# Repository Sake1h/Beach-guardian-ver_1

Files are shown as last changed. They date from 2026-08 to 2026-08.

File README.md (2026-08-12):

ChatGPT Image Aug 12, 2026, 03_50_27 PM

# Beach Guardian

A remotely controlled beach-cleaning rover designed to collect plastic debris from sand while allowing sand to fall back through a mesh sieve.

## Project Overview

Beach Guardian is a robotic prototype designed to help collect plastic waste from sandy environments.

The robot uses a front-mounted scoop with a mesh underside. The scoop can be lowered to collect a mixture of sand and debris. The scoop can then be raised using two servos, allowing sand to fall through the mesh while larger pieces of plastic remain in the scoop.

The robot is controlled through a local Wi-Fi web dashboard and uses two ESP32 microcontrollers.

## Estimated Project Cost

The following is an approximate estimate of the hardware cost for **Beach Guardian V1**. Prices may vary depending on the supplier, brand, and purchase quantity.

| Component | Quantity | Estimated Unit Cost | Estimated Total |
| --- | ---: | ---: | ---: |
| ESP32 Development Board | 2 | $13.00 | $26.00 |
| HC-SR04 Ultrasonic Sensor | 3 | $2.00 | $6.00 |
| L298N Motor Driver | 1 | $3.00 | $3.00 |
| DC Geared Motor | 2 | $10.00 | $20.00 |
| Robot Chassis | 1 | $15.00 | $15.00 |
| Wheels | 2 | $4.00 | $8.00 |
| Servo Motor | 2 | $4.00 | $8.00 |
| Buck Converter | 2 | $3.00 | $6.00 |
| Battery | 1 | $25.00 | $25.00 |
| 1000 µF Capacitors | 3 | $1.00 | $3.00 |
| 1.1 kΩ Resistors | 6 | $0.10 | $0.60 |
| Fuse + Holder | 1 | $3.00 | $3.00 |
| Power Switch | 1 | $2.00 | $2.00 |
| Hook-up / Jumper Wire | Assorted | $5.00 | $5.00 |
| Perfboard | 1 | $3.00 | $3.00 |
| Solder & Miscellaneous Hardware | Assorted | $8.00 | $8.00 |
| **Estimated Total** | | | **~$140 USD** |

 Cost Notes

* The two ESP32 boards were purchased for **5 OMR each**, approximately **$13 USD each**.
* The estimate represents the approximate replacement cost of the hardware used in the project.
* A large reason for the increased prices are due to current geopolitical situations which make shipping charges expensive.
* **Raspberry Pi, webcam, and USB hub are not included**, as the planned plastic/colour recognition system was removed from Beach Guardian V1.
* Development equipment such as a personal computer is not included in the project cost.

## What the Final Prototype Does

- Remote driving through a web dashboard
- Forward, backward, left and right movement
- Motor speed control using PWM
- Three ultrasonic distance sensors
- Live sensor readings displayed on the dashboard
- Two-servo scoop/sieve mechanism
- ESP-NOW communication between the two ESP32s
- 12 V battery-powered drivetrain
- 5 V regulated electronics and servo power
                   
  ChatGPT Image Aug 12, 2026, 03_50_27 PM

 ESP32 #1
- Hosts the Wi-Fi dashboard
- Reads the 3 ultrasonic sensors
- Displays sensor readings
- Receives driving commands from the dashboard
- Sends commands to ESP32 #2 using ESP-NOW

## Firmware

The ESP32 #1 firmware is contained in this repository.

Main source:
src/main.cpp

Supporting modules:
src/dashboard.cpp
src/dashboard.h
src/motors.cpp
src/motors.h

diagram for initial power supply

  ## Software

### ESP32 #1 — Sensor & Dashboard
Responsible for:
- Ultrasonic sensors
- Sensor data
- Web dashboard
- Sending motor commands

[View ESP32 #1 Code](ESP32_1_Sensors/)

### ESP32 #2 — Motor Control
Responsible for:
- Receiving commands
- PWM motor control
- L298N control
- Left/right motor operation

[View ESP32 #2 Code](ESP32_2_Motor_Control/)









full_signal_wiring_final

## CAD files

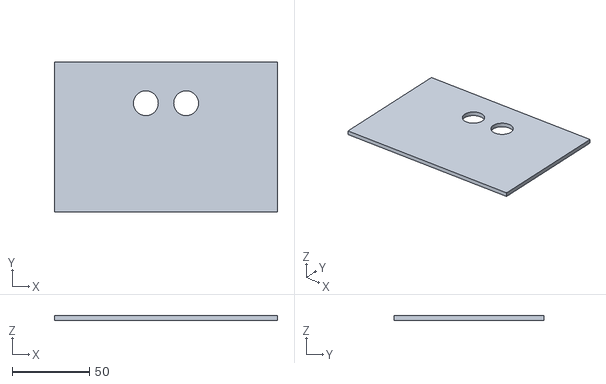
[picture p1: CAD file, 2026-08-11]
hardwarebox front_plate-Body.stl
144.0 x 97.0 x 3.00

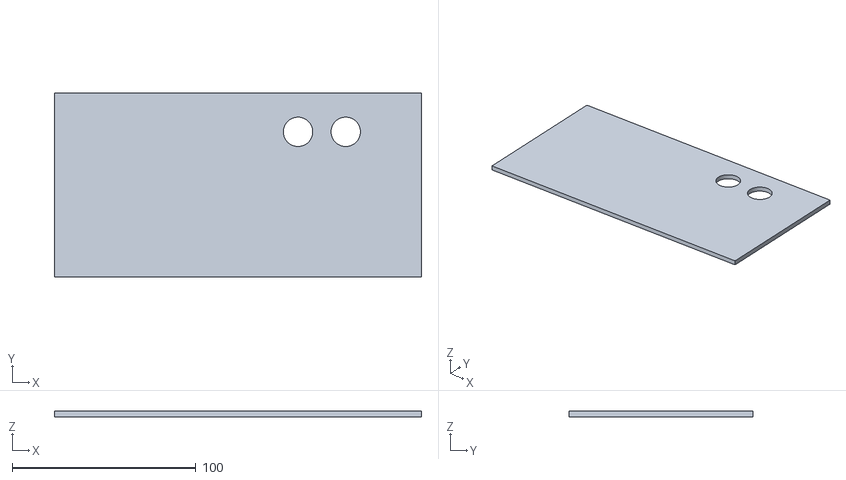
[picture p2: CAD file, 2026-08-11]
hardware box wall (side)-Body.stl
200.0 x 100.0 x 3.00

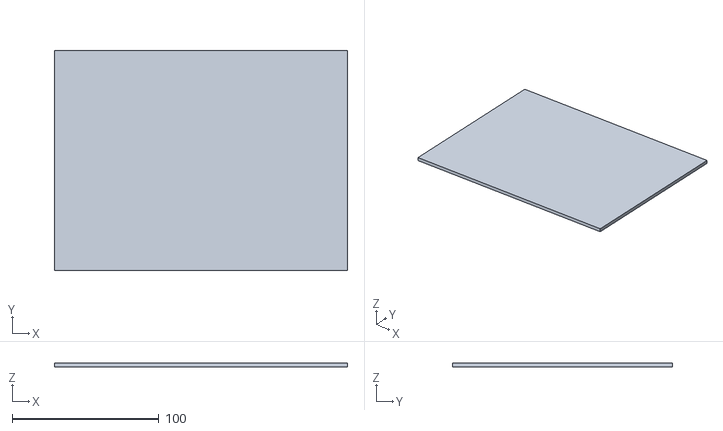
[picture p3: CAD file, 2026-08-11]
floor of hardware enclosure-Body.stl
200.0 x 150.0 x 3.00

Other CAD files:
back plate hardware box-Body.stl

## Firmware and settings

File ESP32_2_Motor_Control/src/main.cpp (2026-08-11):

#include <Arduino.h>
#include <WiFi.h>
#include <esp_now.h>
#include <esp_wifi.h>
#include <ESP32Servo.h>
//l298N pins

// Left motor
#define ENA 18
#define IN1 32
#define IN2 4

// Right motor
#define ENB 19
#define IN3 27
#define IN4 5
//servo pins

#define SERVO1_PIN 13
#define SERVO2_PIN 23

//servo positions
#define SERVO1_DOWN 90
#define SERVO1_UP   135
#define SERVO2_DOWN 90
#define SERVO2_UP   45
Servo sieveServo1;
Servo sieveServo2;
//pwm settings
#define PWM_FREQ 1000
#define PWM_RESOLUTION 8
#define PWM_CHANNEL_A 0
#define PWM_CHANNEL_B 1
//espnow
typedef struct {
    int leftSpeed;
    int rightSpeed;
    int sieveActive;
} ControlMessage;
ControlMessage receivedCommand;

//motor control function

void setMotor(
    int speed,
    int in1,
    int in2,
    int pwmChannel
) {
    speed = constrain(speed, -255, 255);
    if (speed > 0) {
        digitalWrite(in1, HIGH);
        digitalWrite(in2, LOW);
        ledcWrite(
            pwmChannel,
            speed
        );
    }
    else if (speed < 0) {
        digitalWrite(in1, LOW);
        digitalWrite(in2, HIGH);
        ledcWrite(
            pwmChannel,
            -speed
        );
    }

    else {
        digitalWrite(in1, LOW);
        digitalWrite(in2, LOW);
        ledcWrite(
            pwmChannel,
            0
        );}}
//both motors control function
void setMotorSpeeds(
    int leftSpeed,
    int rightSpeed
) {
    setMotor(
        leftSpeed,
        IN1,
        IN2,
        PWM_CHANNEL_A
    );

    setMotor(
        rightSpeed,
        IN3,
        IN4,
        PWM_CHANNEL_B
    );
}
//stop both motors

void stopMotors() {
    setMotorSpeeds(0, 0);
}

void onDataReceive(
    const uint8_t *mac,
    const uint8_t *incomingData,
    int len
) {
    if (len != sizeof(ControlMessage)) {

        Serial.print("Invalid packet size: ");
        Serial.println(len);

        return;}
    // Copy received command
    memcpy(
        &receivedCommand,
        incomingData,
        sizeof(receivedCommand)
    );
//motor commands
    setMotorSpeeds(
        receivedCommand.leftSpeed,
        receivedCommand.rightSpeed
    );
//sieve control
    if (receivedCommand.sieveActive) {

        // Lift / tilt scoop
        sieveServo1.write(SERVO1_UP);
        sieveServo2.write(SERVO2_UP);

    } else {
        // Lower scoop
        sieveServo1.write(SERVO1_DOWN);
        sieveServo2.write(SERVO2_DOWN);
    }

    Serial.print("Left: ");
    Serial.print(receivedCommand.leftSpeed);

    Serial.print(" | Right: ");
    Serial.print(receivedCommand.rightSpeed);

    Serial.print(" | Sieve: ");
    Serial.println(receivedCommand.sieveActive);
}

//setup function
void setup() {

    Serial.begin(115200);

    delay(1000);
//motrs pins setup
    pinMode(IN1, OUTPUT);
    pinMode(IN2, OUTPUT);
    pinMode(IN3, OUTPUT);
    pinMode(IN4, OUTPUT);
//pwm
    ledcSetup(
        PWM_CHANNEL_A,
        PWM_FREQ,
        PWM_RESOLUTION
    );
    ledcSetup(
        PWM_CHANNEL_B,
        PWM_FREQ,
        PWM_RESOLUTION
    );
    ledcAttachPin(
        ENA,
        PWM_CHANNEL_A
    );
    ledcAttachPin(
        ENB,
        PWM_CHANNEL_B
    );
    stopMotors();
//servo setup
    sieveServo1.setPeriodHertz(50);
    sieveServo2.setPeriodHertz(50);

    sieveServo1.attach(
        SERVO1_PIN,
        500,
        2400
    );
    sieveServo2.attach(
        SERVO2_PIN,
        500,
        2400
    );
    // Start with scoop lowered
    sieveServo1.write(SERVO1_DOWN);
    sieveServo2.write(SERVO2_DOWN);
//wifi
    WiFi.mode(WIFI_STA);

    // ESP1 uses ESP-NOW channel 1
    esp_wifi_set_channel(
        1,
        WIFI_SECOND_CHAN_NONE
    );

    Serial.println();
    Serial.println(" BEACH GUARDIAN ESP32-B");
    Serial.print("ESP32-B MAC: ");
    Serial.println(WiFi.macAddress());

    //init esp now
    if (esp_now_init() != ESP_OK) {

        Serial.println(
            "ESP-NOW initialization FAILED"
        );

        return;
    }

    esp_now_register_recv_cb(
        onDataReceive
    );

    Serial.println(
        "ESP-NOW receiver ready."
    );

    Serial.println(
        "Waiting for commands..."
    );
}//final loop
void loop() {
    delay(10);
}

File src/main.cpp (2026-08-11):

#include <Arduino.h>
#include <WiFi.h>
#include <WebServer.h>
#include <esp_now.h>

//Esp #2's mac
uint8_t esp2Address[] = {
    0xEC, 0xE3, 0x34, 0x45, 0xAB, 0xE4};

//esp now channel
const int ESPNOW_CHANNEL = 1;

//Ultrasonic sensor pins

// FRONT
const int TRIG1 = 12;
const int ECHO1 = 14;

// LEFT
const int TRIG2 = 27;
const int ECHO2 = 26;

// RIGHT
const int TRIG3 = 25;
const int ECHO3 = 33;

typedef struct {
    int leftSpeed;
    int rightSpeed;
    int sieveActive;
} ControlMessage;

ControlMessage cmdData;

//sensor readings

float distance1 = 0;
float distance2 = 0;
float distance3 = 0;

//peer info for esp-now

esp_now_peer_info_t peerInfo;

//sieve state
bool sieveState = false;
//auto mode state
bool autoMode = false;

//server/ dashboard
const char* ap_ssid = "Beach Guardian";
const char* ap_pass = "beachguardian";

WebServer server(80);// dahsboard underneath
const char htmlPage[] = R"rawliteral(

<!DOCTYPE html>
<html>
<head>
<meta name="viewport" content="width=device-width, initial-scale=1">
<title>Beach Guardian</title>
<style>
body {
    font-family: Arial;
    text-align: center;
}
button {
    width: 110px;
    height: 60px;
    margin: 5px;
    font-size: 18px;}
</style>
</head>
<body>
<h1>BEACH GUARDIAN</h1>
<button onclick="sendCommand('forward')">
Forward
</button>
<br>
<button onclick="sendCommand('left')">
Left
</button>
<button onclick="sendCommand('stop')">
STOP
</button>

<button onclick="sendCommand('right')">
Right
</button>

<br>
<button onclick="sendCommand('backward')">
Backward
</button>
<br><br>
<button onclick="sendCommand('sieve')">
Sieve
</button>
<br><br>
<button onclick="toggleAuto()">
AUTO / MANUAL
</button>
<h3>
Mode:
<span id="mode">MANUAL</span>
</h3>
<hr>
<p>
Front:
<span id="front">--</span>
cm
</p>
<p>
Left:
<span id="left">--</span>
cm
</p>
<p>
Right:
<span id="right">--</span>
cm
</p>
<script>
function sendCommand(command) {

    fetch('/cmd?command=' + command);      

}

function toggleAuto() {

    fetch('/auto')
    .then(response => response.text())
    .then(data => {
        document.getElementById("mode").innerText = data;
    });}
function updateSensors() {
    fetch('/sensors')
    .then(response => response.json())
    .then(data => {

        document.getElementById("front").innerText =
            data.front;

        document.getElementById("left").innerText =
            data.left;

        document.getElementById("right").innerText =
            data.right;
    });
}

setInterval(updateSensors, 500);
updateSensors();
</script>
</body>
</html>
)rawliteral";

//Sensor reading function
float readUltrasonic(
    int trigPin,
    int echoPin
) {
    digitalWrite(
        trigPin,
        LOW
    );
    delayMicroseconds(2);
    digitalWrite(
        trigPin,
        HIGH
    );
    delayMicroseconds(10);
    digitalWrite(
        trigPin,
        LOW
    );
    unsigned long duration =
        pulseIn(
            echoPin,
            HIGH,
            30000
        );

    if (duration == 0) {

        return -1.0;

    }

    return duration / 58.0;
}

void readSensors() {

    distance1 =
        readUltrasonic(
            TRIG1,
            ECHO1
        );

    delay(5);

    distance2 =
        readUltrasonic(
            TRIG2,
            ECHO2
        );

    delay(5);

    distance3 =
        readUltrasonic(
            TRIG3,
            ECHO3
        );
}

void sendEspNowCommand() {

    esp_err_t result =
        esp_now_send(
            esp2Address,
            (uint8_t*)&cmdData,
            sizeof(cmdData)
        );

    if (result == ESP_OK) {

        Serial.println(
            "ESP-NOW command sent"
        );

    }
    else {

        Serial.println(
            "ESP-NOW send failed"
        );
    }
}
void handleRoot() {

    server.send(
        200,
        "text/html",
        htmlPage
    );
}
//manual control commands
void handleCommand() {
    String command =
        server.arg("command");

    Serial.print(
        "Command: "
    );
    Serial.println(command);

    // Manual control disabled in AUTO
    if (autoMode) {

        server.send(
            200,
            "text/plain",
            "AUTO MODE ACTIVE"
        );
        return;
    }
    // FORWARD
    if (command == "forward") {

        cmdData.leftSpeed = 60;
        cmdData.rightSpeed = 60;
    }
    // BACKWARD
    else if (command == "backward") {
        cmdData.leftSpeed = -60;
        cmdData.rightSpeed = -60;
    }
    // LEFT
    else if (command == "left") {
        cmdData.leftSpeed = -50;
        cmdData.rightSpeed = 50;
    }

    // RIGHT
    else if (command == "right") {

        cmdData.leftSpeed = 50;
        cmdData.rightSpeed = -50;
    }

    // STOP
    else if (command == "stop") {

        cmdData.leftSpeed = 0;
        cmdData.rightSpeed = 0;
    }
    // SIEVE
    else if (command == "sieve") {

        sieveState = !sieveState;

        cmdData.sieveActive =
            sieveState ? 1 : 0;
    }
    else {
        server.send(
            400,
            "text/plain",
            "Unknown command"
        );

        return;
    }
    sendEspNowCommand();

    server.send(
        200,
        "text/plain",
        command
    );
}
void handleAutoMode() {

    autoMode = !autoMode;

    // Stop when switching modes
    cmdData.leftSpeed = 0;
    cmdData.rightSpeed = 0;

    sendEspNowCommand();

    if (autoMode) {

        Serial.println(
            "AUTO MODE ON"
        );

        server.send(
            200,
            "text/plain",
            "AUTO"
        );

    }
    else {

        Serial.println(
            "MANUAL MODE ON"
        );

        server.send(
            200,
            "text/plain",
            "MANUAL"
        );
    }
}

void handleSensors() {

    String json = "{";

    json += "\"front\":";
    json += String(
        distance1,
        1
    );

    json += ",\"left\":";
    json += String(
        distance2,
        1
    );

    json += ",\"right\":";
    json += String(
        distance3,
        1
    );

    json += "}";

    server.send(
        200,
        "application/json",
        json
    );
}
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

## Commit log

2026-07-25 Fix duplicate entries in Bill of Materials
    Removed duplicate entries in the Bill of Materials section.
2026-07-30 Add PlatformIO project files: ESP32 Wi-Fi dashboard
2026-07-30 Add files via upload
    This is the hardware-holding box which will have an airtight seal. The box has an 8mm hole to allow wires to be connected. It will house motor drivers, the ESP, buck converter, switches etc...
    height=50mm
    length=134mm
    width=94mm
    [Beach guardian-Body.stl]
2026-07-31 Document soldering of voltage divider and GPIO routing
2026-08-07 The updated upper chassis & hardware box
    chassis dimensions:
    WIDTH:150MM
    LENGTH:200MM
    HEIGHT:103MM
    CIRCULAR HOLE CUT-OUTS (Ultrasonic sensors):16MM each
    GAP (between each pair of holes): 10MM
    [back plate hardware box-Body.stl, floor of hardware enclosure-Body.stl, hardware box wall (side)-Body.stl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]
2026-08-08 Revise Bill of Materials with new components
    Updated the Bill of Materials section with additional components and specifications.
2026-08-11 Add ESP32 #2 motor control project
2026-08-11 Add Bill of Materials for project components
2026-08-11 Create ESP pins and wiring
2026-08-11 Add full signal wiring image to README
    Added an additional image to the README file.
2026-08-12 Update wiring diagram in README
    Removed old wiring diagram and added a new image.
2026-10-20 Revise Bill of Materials with updated components
    Updated battery specification and confirmed quantities for capacitors. Removed fuse entry and clarified wheel entry.
2026-11-06 Insert image into Media
    Add an image to the Media file.
